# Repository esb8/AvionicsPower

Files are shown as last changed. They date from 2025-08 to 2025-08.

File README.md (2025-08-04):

## Overview

This project is a custom RP2040-based **Power Distribution Board**, designed for use in an avionics stack comprising three CAN-connected PCBs:  
- Sensor Board  
- Power Distribution Board **(this board)** 
- GPS Board

The system is intended for **high-power model rocketry**, and this board’s primary role is to **distribute power** to the rest of the system while also managing essential subsystems such as communication, monitoring, and recovery signaling.

---

## 📡 PCB Features

- High-current 3.3 V synchronous buck converter (up to 3 A), operating at 1.5 MHz and ~95% efficiency  
- Low-noise LDO with 60 dB PSRR @ 100 Hz, delivering up to 500 mA at 3.3 V  
- Single-cell Li-ion/LiPo battery protection IC with over-voltage, under-voltage, and over-current protection  
- CAN controller and transceiver  
- RP2040 microcontroller  
- USB-C interface  
- Onboard status LEDs for buck converter, MCU status, and USB-C diagnostics  
- External 128 Mbit W25Q128JVS flash memory  
- MAX98357A I²S digital amplifier connected to a speaker for audible recovery

---

## ✅ PCB Design Criteria

This board was designed to meet the following system-level criteria:

- **Stable, low-noise 3.3 V rail** for analog/digital loads — supports up to 500 mA with minimal line/load regulation (target: ±0.1%)
- **High-current 3.3 V rail** capable of supplying up to 3 A to downstream PCBs
- **Battery protection** for a 1S LiPo cell, including self-recovery from under-voltage and short-circuit protection
- **CAN bus communication interface** to enable modular system design with multiple nodes
- **Audible recovery system** — implemented using the **MAX98357A I²S Class-D amplifier**, which drives a speaker directly from the RP2040 using digital audio

---

## 📷 Media

**Schematic**  
Schematic

**PCB Layout**  
PCB

**3D Model**  
3D Model

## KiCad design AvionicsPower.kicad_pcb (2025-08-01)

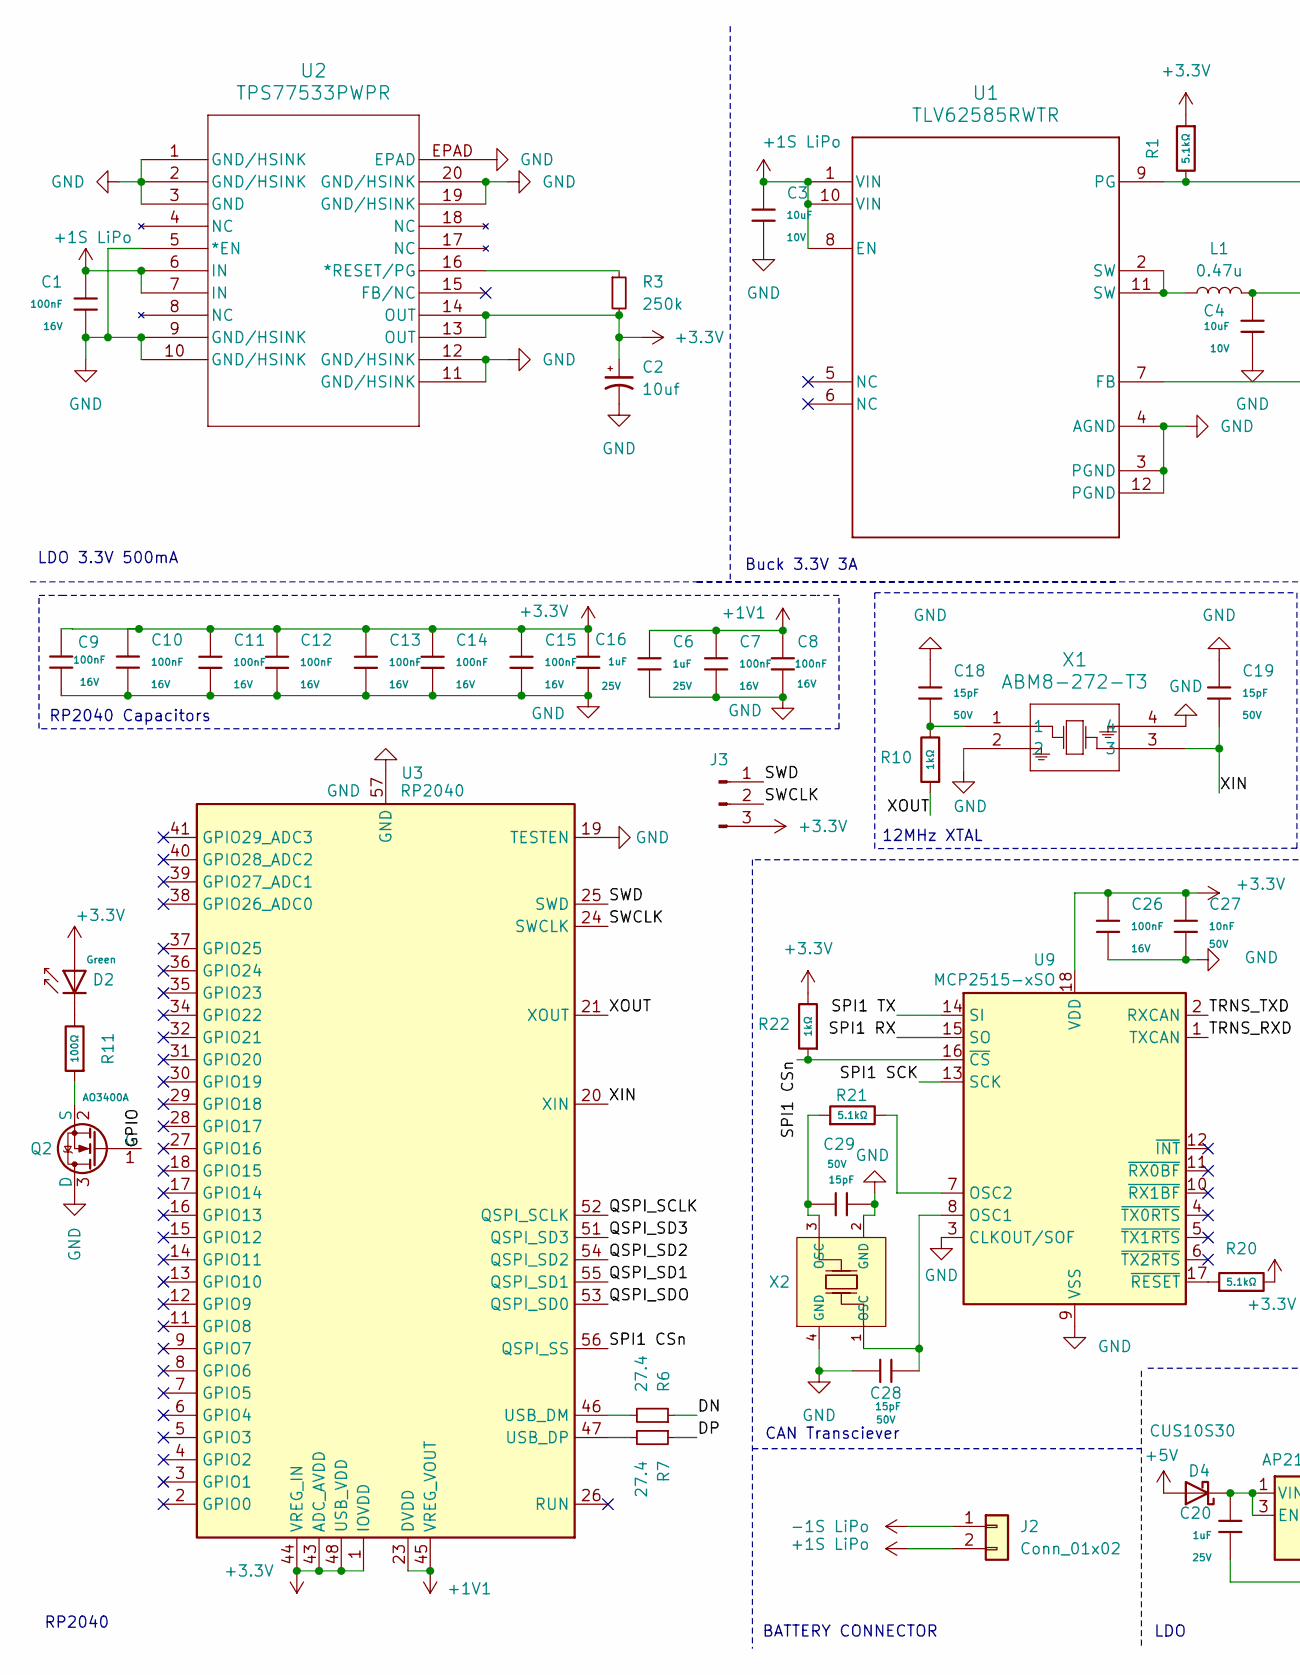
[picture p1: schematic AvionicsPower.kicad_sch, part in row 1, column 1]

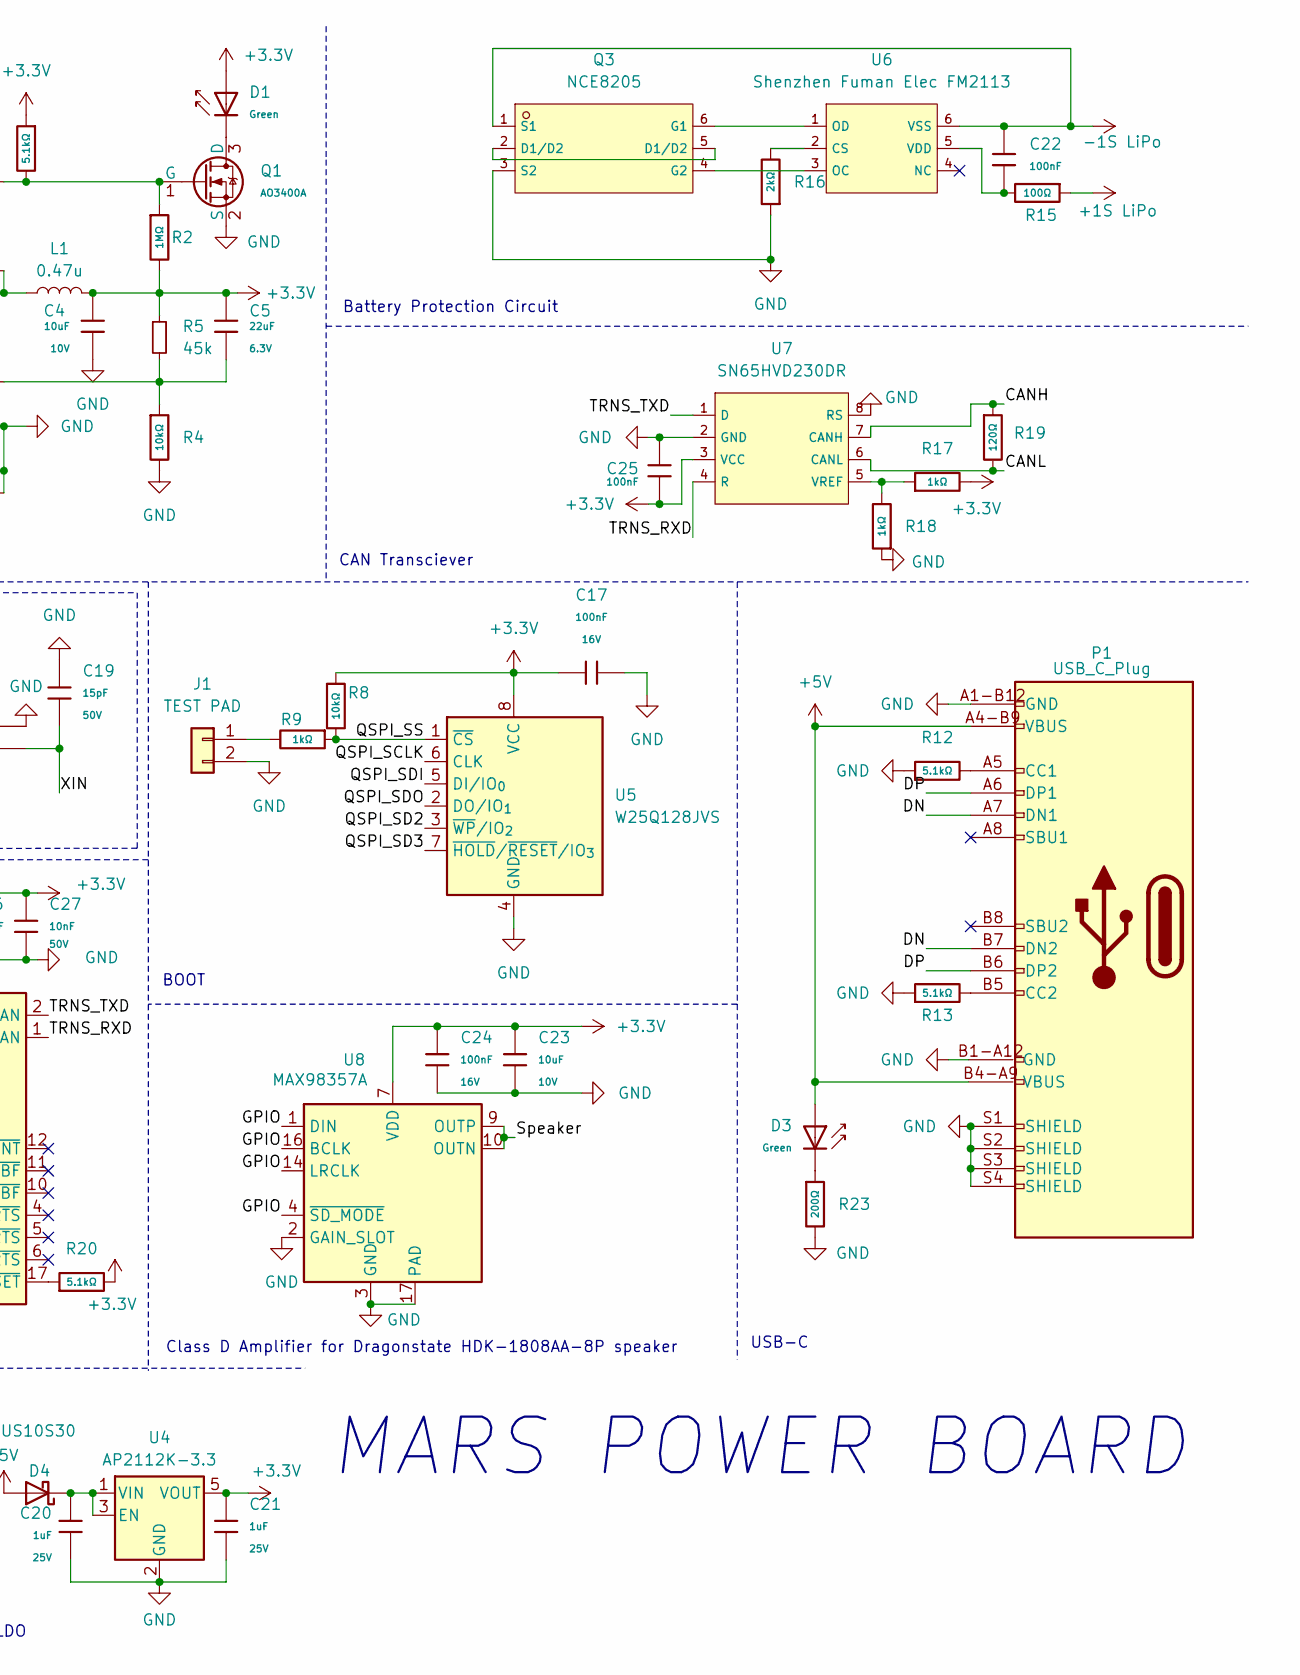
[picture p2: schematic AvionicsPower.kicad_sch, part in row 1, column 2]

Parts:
C1, C7, C8, C9, C10, C11, C12, C13, C14, C15, C17, C22, C24, C25, C26: 100nF; C_0402; Voltage Rated 16V; Tolerance ±10%; Part CL05B104KO5NNNC; LCSC C1525
C2: 10uf; C_0805; LCSC C696821
C3, C4, C23: 10uF; C_0603; Voltage Rated 10V; Tolerance ±10%; Part CL10A106KP8NNNC; LCSC C19702
C5: 22uF; C_0603; Voltage Rated 6.3V; Tolerance ±20%; Part CL10A226MQ8NRNC; LCSC C59461
C6, C16, C20, C21: 1uF; C_0402; Voltage Rated 25V; Tolerance ±10%; Part CL05A105KA5NQNC; LCSC C52923
C18, C19, C28, C29: 15pF; C_0402; Voltage Rated 50V; Tolerance ±5%; Part 0402CG150J500NT; LCSC C1548
C27: 10nF; C_0402; Voltage Rated 50V; Tolerance ±10%; Part CL05B103KB5NNNC; LCSC C15195
D1, D2, D3: Green; D_0805; Part KT-0805G; LCSC C2297
D4: CUS10S30; D_SOD-323; LCSC C146335
J1: TEST PAD
J2: Conn_01x02; AMASS_XT60PW-M_1x02_P7.20mm_Horizontal; LCSC C131337
J3: Conn_01x03_Pin
L1: 0.47u
P1: USB_C_Plug; USB_C_Receptacle_GCT_USB4105-xx-A_16P_TopMnt_Horizontal
Q1, Q2: AO3400A; Q_SOT-23; Part AO3400A; LCSC C20917
Q3: NCE8205; SOT-23-6_L2.9-W1.6-P0.95-LS2.8-BR; LCSC C502858
R1, R12, R13, R20, R21: 5.1kΩ; R_0402_1005Metric; Overload Voltage (Max) 50V; Tolerance ±1%; Part 0402WGF5101TCE; LCSC C25905
R2: 1MΩ; R_0603_1608Metric; Overload Voltage (Max) 75V; Tolerance ±1%; Part 0603WAF1004T5E; LCSC C22935
R3: 250k; R_1206; LCSC C2828893
R4: 10kΩ; R_0805; Overload Voltage (Max) 150V; Tolerance ±1%; Part 0805W8F1002T5E; LCSC C17414
R5: 45k
R6, R7: 27.4; C_0402_1005Metric; LCSC C850920
R8: 10kΩ; R_0402_1005Metric; Overload Voltage (Max) 50V; Tolerance ±1%; Part 0402WGF1002TCE; LCSC C25744
R9, R10, R17, R18, R22: 1kΩ; R_0402_1005Metric; Overload Voltage (Max) 50V; Tolerance ±1%; Part 0402WGF1001TCE; LCSC C11702
R11, R15: 100Ω; R_0402_1005Metric; Overload Voltage (Max) 50V; Tolerance ±1%; Part 0402WGF1000TCE; LCSC C25076
R16: 2kΩ; R_0402_1005Metric; Overload Voltage (Max) 50V; Tolerance ±1%; Part 0402WGF2001TCE; LCSC C4109
R19: 120Ω; R_0402_1005Metric; Overload Voltage (Max) 50V; Tolerance ±1%; Part 0402WGF1200TCE; LCSC C25079
R23: 200Ω; R_0402; Overload Voltage (Max) 50V; Tolerance ±1%; Part 0402WGF2000TCE; LCSC C25087
U1: TLV62585RWTR; RWT0012A
U2: TPS77533PWPR; PWP20_3P38X2P4
U3: RP2040; QFN-56-1EP_7x7mm_P0.4mm_EP3.2x3.2mm
U4: AP2112K-3.3; SOT-23-5
U5: W25Q128JVS; SOIC-8_5.3x5.3mm_P1.27mm
U6: Shenzhen Fuman Elec FM2113; SOT-23-6_L2.9-W1.6-P0.95-LS2.8-BL; LCSC C2832124
U7: SN65HVD230DR; SOIC-8_L4.9-W3.9-P1.27-LS6.0-BL; Supply Voltage 3V~3.6V; Part SN65HVD230DR; LCSC C12084
U8: MAX98357A; TQFN-16-1EP_3x3mm_P0.5mm_EP1.23x1.23mm
U9: MCP2515-xSO; QFN-20-1EP_4x4mm_P0.5mm_EP2.5x2.5mm
X1: ABM8-272-T3; Crystal_SMD_3225-4Pin_3.2x2.5mm
X2: X322512MSB4SI; CRYSTAL-SMD_4P-L3.2-W2.5-BL; Frequency Tolerance ±10ppm; Part X322512MSB4SI; LCSC C9002

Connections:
+1S LiPo: C1.1, C3.1, J2.2, R15.1, U1.1 (VIN), U1.8 (EN), U1.10 (VIN), U2.6 (IN), U2.7 (IN)
+1V1: C6.1, C7.1, C8.1, U3.23 (DVDD), U3.45 (VREG_VOUT), U3.50 (DVDD)
+3.3V: C2.1, C4.1, C5.1, C9.1, C10.1, C11.1, C12.1, C13.1, C14.1, C15.1, C16.1, C17.1, C21.1, C23.1, C24.1, C25.2, C26.1, C27.1, D1.2, D2.2, J3.3, L1.2, R1.1, R2.2, R3.2, R5.1, R8.1, R17.2, R20.2, R22.2, U2.13 (OUT), U2.14 (OUT), U3.1 (IOVDD), U3.10 (IOVDD), U3.22 (IOVDD), U3.33 (IOVDD), U3.42 (IOVDD), U3.43 (ADC_AVDD), U3.44 (VREG_IN), U3.48 (USB_VDD), U3.49 (IOVDD), U4.5 (VOUT), U5.8 (VCC), U7.3 (VCC), U8.7 (VDD), U8.8 (VDD), U9.18 (VDD)
+5V: D3.2, D4.2 (A), P1.A4-B9 (VBUS), P1.B4-A9 (VBUS)
-1S LiPo: C22.1, J2.1, Q3.1 (S1), U6.6 (VSS)
/CANH: R19.1, U7.7 (CANH)
/CANL: R19.2, U7.6 (CANL)
/DN: P1.A7 (DN1), P1.B7 (DN2), R6.1
/DP: P1.A6 (DP1), P1.B6 (DP2), R7.1
/GPIO: Q2.1 (G), U8.1 (DIN), U8.4 (~SD_MODE), U8.14 (LRCLK), U8.16 (BCLK)
/QSPI_SCLK: U3.52 (QSPI_SCLK), U5.6 (CLK)
/QSPI_SD1: U3.55 (QSPI_SD1)
/QSPI_SD2: U3.54 (QSPI_SD2), U5.3 (~WP/IO_{2})
/QSPI_SD3: U3.51 (QSPI_SD3), U5.7 (~HOLD/~RESET/IO_{3})
/QSPI_SDI: U5.5 (DI/IO_{0})
/QSPI_SDO: U3.53 (QSPI_SD0), U5.2 (DO/IO_{1})
/QSPI_SS: R8.2, R9.1, U5.1 (~CS)
/SPI1 CSn: R22.1, U3.56 (QSPI_SS), U9.16 (~CS)
/SPI1 RX: U9.15 (SO)
/SPI1 SCK: U9.13 (SCK)
/SPI1 TX: U9.14 (SI)
/SWCLK: J3.2, U3.24 (SWCLK)
/SWD: J3.1, U3.25 (SWD)
/Speaker: U8.9 (OUTP), U8.10 (OUTN)
/TRNS_RXD: U7.4 (R), U9.1 (TXCAN)
/TRNS_TXD: U7.1 (D), U9.2 (RXCAN)
/XIN: C19.2, U3.20 (XIN), X1.3
/XOUT: R10.1, U3.21 (XOUT)
GND: C1.2, C2.2, C3.2, C4.2, C6.2, C7.2, C8.2, C9.2, C10.2, C11.2, C12.2, C13.2, C14.2, C15.2, C16.2, C17.2, C18.1, C19.1, C20.1, C21.2, C23.2, C24.2, C25.1, C26.2, C27.2, C28.1, C29.1, J1.2, P1.A1-B12 (GND), P1.B1-A12 (GND), P1.S1 (SHIELD), P1.S2 (SHIELD), P1.S3 (SHIELD), P1.S4 (SHIELD), Q1.2 (S), Q2.3 (D), Q3.3 (S2), R4.2, R12.1, R13.1, R16.1, R18.1, R23.2, U1.3 (PGND), U1.4 (AGND), U1.12 (PGND), U2.1 (GND/HSINK), U2.2 (GND/HSINK), U2.3 (GND), U2.5 (*EN), U2.9 (GND/HSINK), U2.10 (GND/HSINK), U2.11 (GND/HSINK), U2.12 (GND/HSINK), U2.19 (GND/HSINK), U2.20 (GND/HSINK), U2.EPAD, U3.19 (TESTEN), U3.57 (GND), U4.2 (GND), U5.4 (GND), U7.2 (GND), U7.8 (RS), U8.2 (GAIN_SLOT), U8.3 (GND), U8.11 (GND), U8.15 (GND), U8.17 (PAD), U9.3 (CLKOUT/SOF), U9.9 (VSS), X1.2, X1.4, X2.2 (GND), X2.4 (GND)
unnamed: C18.2, R10.2, X1.1
unnamed: C29.2, R21.1, X2.3 (OSC)
unnamed: D2.1, R11.2
unnamed: D3.1, R23.1
unnamed: C20.2, D4.1 (K), U4.1 (VIN), U4.3 (EN)
unnamed: J1.1, R9.2
unnamed: L1.1, U1.2 (SW), U1.11 (SW)
unnamed: P1.A5 (CC1), R12.2
unnamed: P1.B5 (CC2), R13.2
unnamed: D1.1, Q1.3 (D)
unnamed: Q1.1 (G), R1.2, R2.1, U1.9 (PG)
unnamed: Q2.2 (S), R11.1
unnamed: Q3.2 (D1/D2), Q3.5 (D1/D2)
unnamed: Q3.6 (G1), U6.1 (OD)
unnamed: Q3.4 (G2), U6.3 (OC)
unnamed: C5.2, R4.1, R5.2, U1.7 (FB)
unnamed: R3.1, U2.16 (*RESET/PG)
unnamed: R6.2, U3.46 (USB_DM)
unnamed: R7.2, U3.47 (USB_DP)
unnamed: R16.2, U6.2 (CS)
unnamed: C22.2, R15.2, U6.5 (VDD)
unnamed: R17.1, R18.2, U7.5 (VREF)
unnamed: C28.2, U9.8 (OSC1), X2.1 (OSC)
unnamed: R21.2, U9.7 (OSC2)
unnamed: R20.1, U9.17 (~RESET)

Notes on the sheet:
LDO
RP2040 Capacitors
MARS POWER BOARD
CAN Transciever
BATTERY CONNECTOR
BOOT
RP2040
12MHz XTAL
LDO 3.3V 500mA
USB-C
Class D Amplifier for Dragonstate HDK-1808AA-8P speaker
Battery Protection Circuit
Buck 3.3V 3A

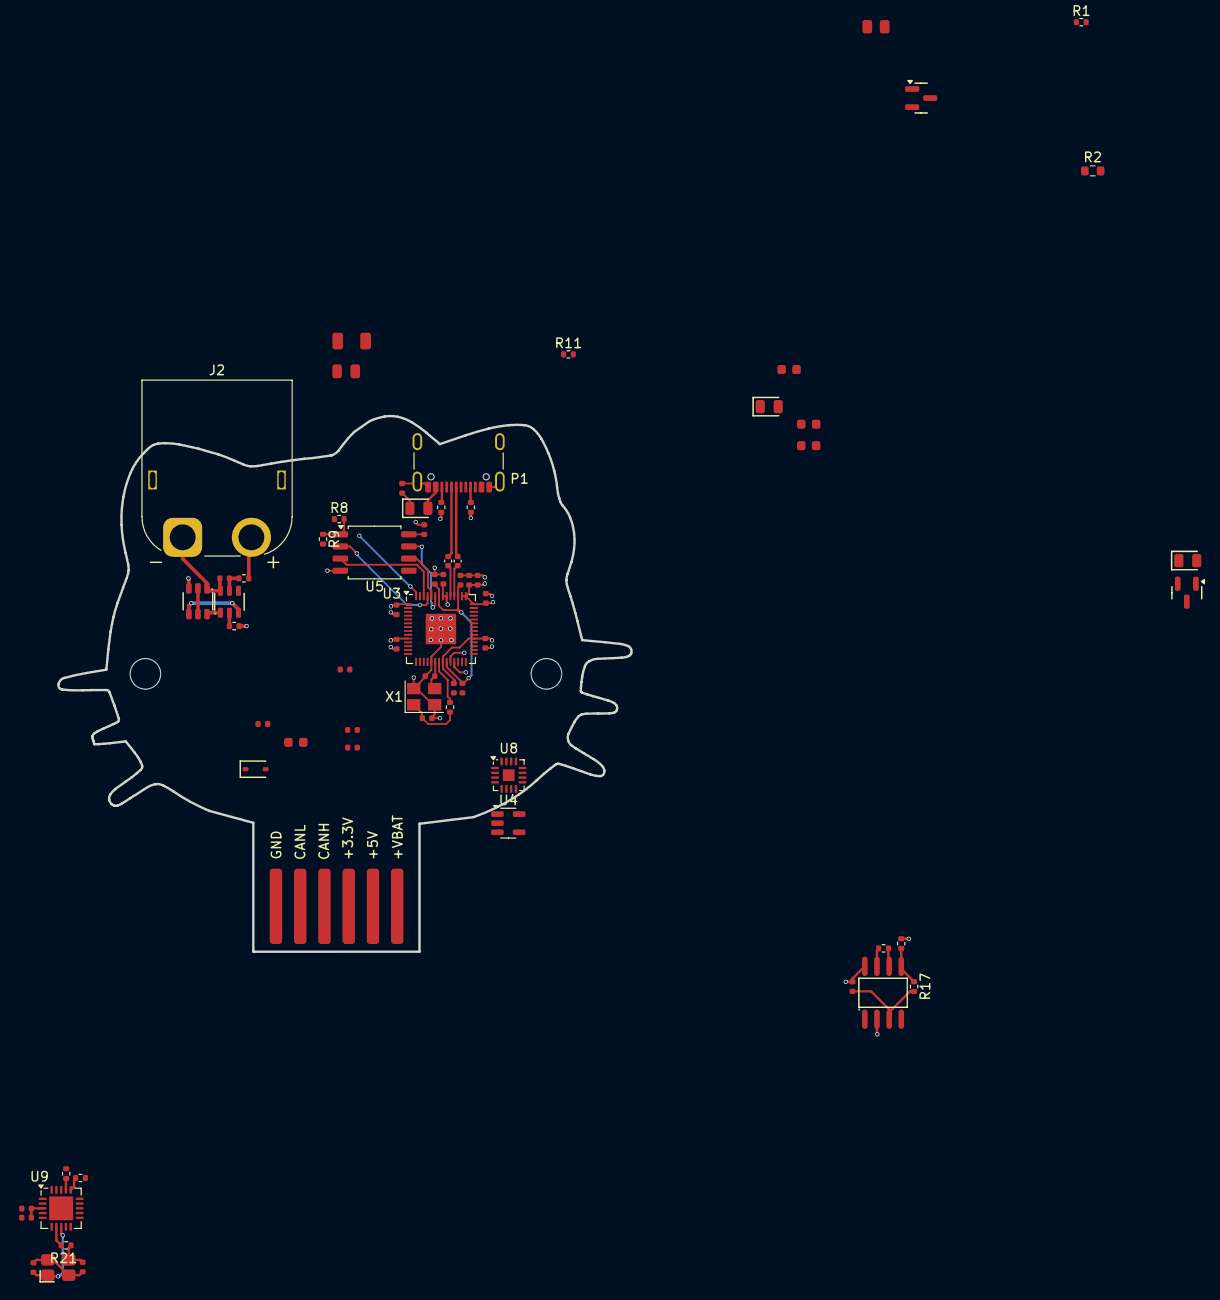
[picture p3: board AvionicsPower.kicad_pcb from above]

Board: 2 copper layers, 60.0 x 56.1 mm, 68 parts (0 on the bottom side), 44 nets.

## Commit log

2025-07-03 Added LDO
    [AvionicsPower.kicad_pcb, AvionicsPower.kicad_sch]
2025-07-04 Added Buck Converter
    [AvionicsPower.kicad_pcb, AvionicsPower.kicad_sch]
2025-07-04 Added USB-C Connector, Added LDO, Added RP2040, Added Debug LEDs
    [AvionicsPower.kicad_sch]
2025-07-05 Added Battery Management IC
    [AvionicsPower.kicad_sch]
2025-07-05 Added Class D Amplifier and Speaker
    [AvionicsPower.kicad_sch]
2025-07-05 Added CAN Controller and Transciever, finalized schematic
    [AvionicsPower.kicad_sch]
2025-07-30 Began PCB Layout
    [AvionicsPower.kicad_pcb, AvionicsPower.kicad_sch]
2025-08-01 basic layout
    [AvionicsPower.kicad_pcb, AvionicsPower.kicad_sch]
2025-08-02 Finalized PCB layout.
    [AvionicsPower.kicad_sch]
2025-08-04 Changed connector, passed DRC, finalized PCB design
    [AvionicsPower.kicad_sch]
